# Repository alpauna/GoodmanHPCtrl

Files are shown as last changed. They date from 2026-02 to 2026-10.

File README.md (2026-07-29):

# GoodmanHPCtrl

ESP32-based controller for Goodman heatpumps with support for cooling, heating, and defrost modes.

> **⚠ Security note:** The device's web interface is plain HTTP only (no built-in TLS). For any access beyond a trusted local LAN, run it behind an HTTPS-terminating reverse proxy (Pangolin, Caddy, nginx, Cloudflare Tunnel, Tailscale Funnel, etc.) — never expose port 80 directly to an untrusted network. See [Network Access](#network-access).

## Web Interface

| Page | Screenshot |
|---|---|
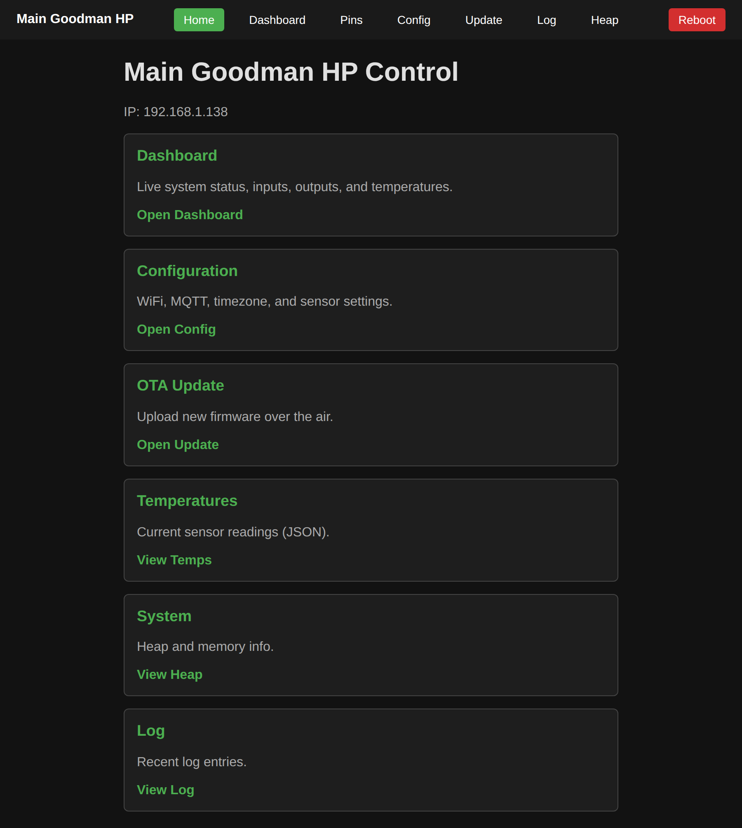
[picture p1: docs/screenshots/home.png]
Home
| Home |  |
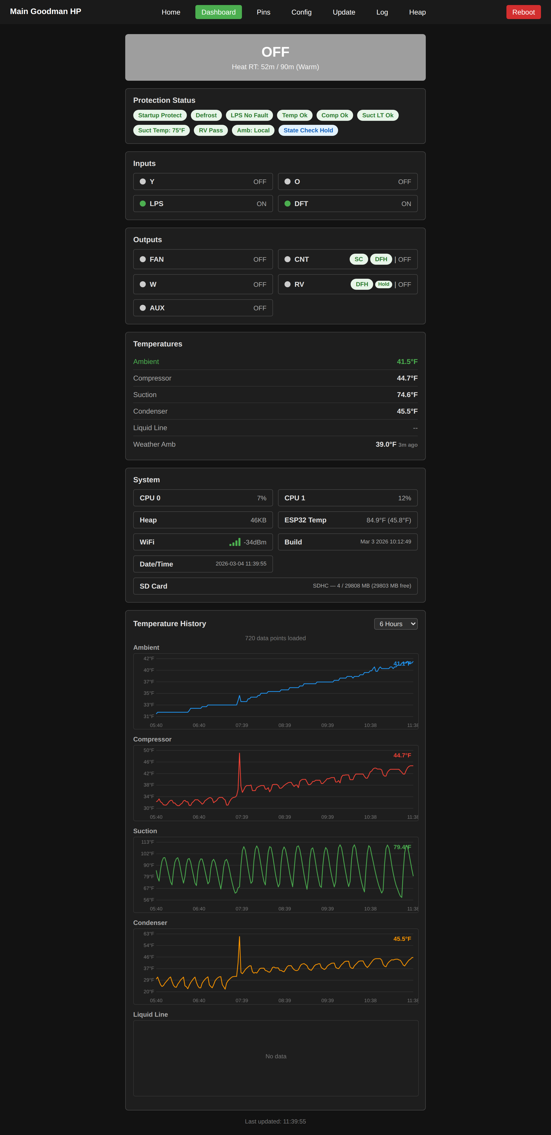
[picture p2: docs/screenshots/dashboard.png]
Dashboard
| Dashboard |  |
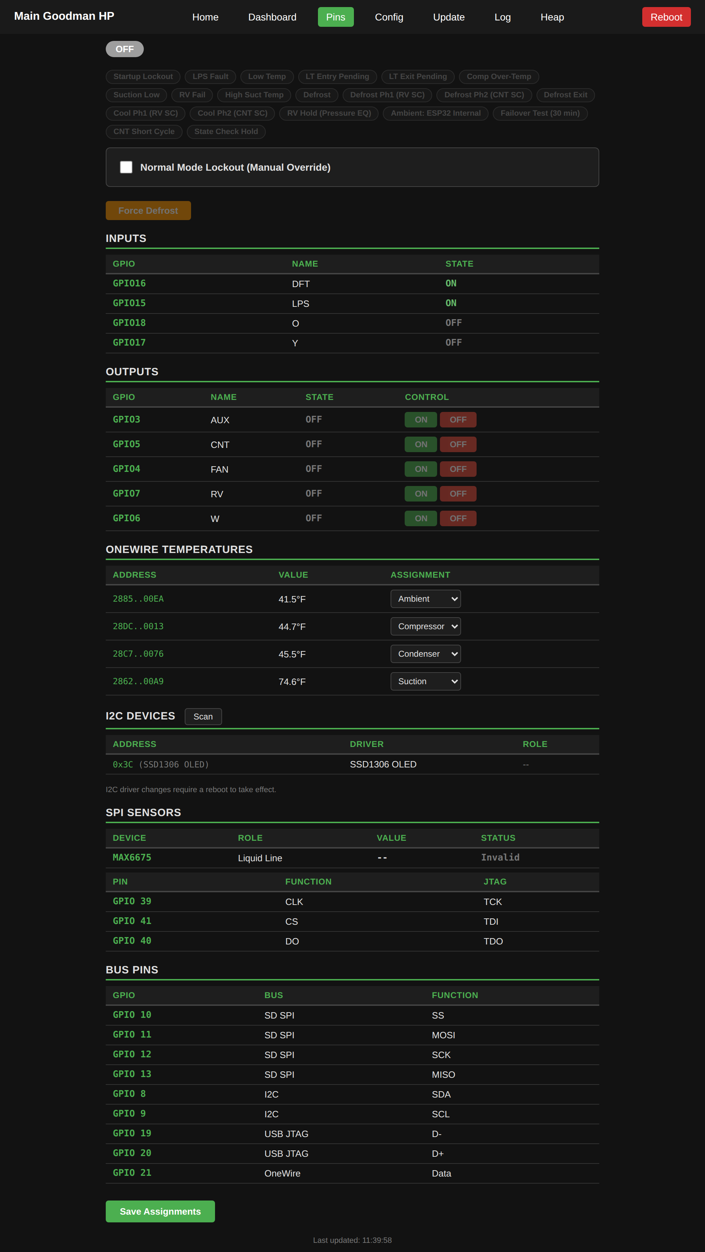
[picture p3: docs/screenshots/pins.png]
Pins
| Pins |  |
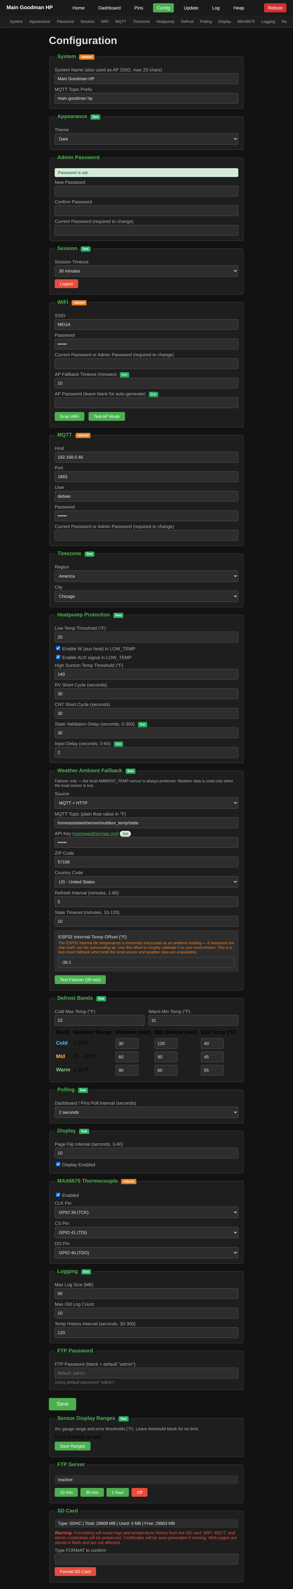
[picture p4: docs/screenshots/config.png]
Configuration
| Configuration |  |
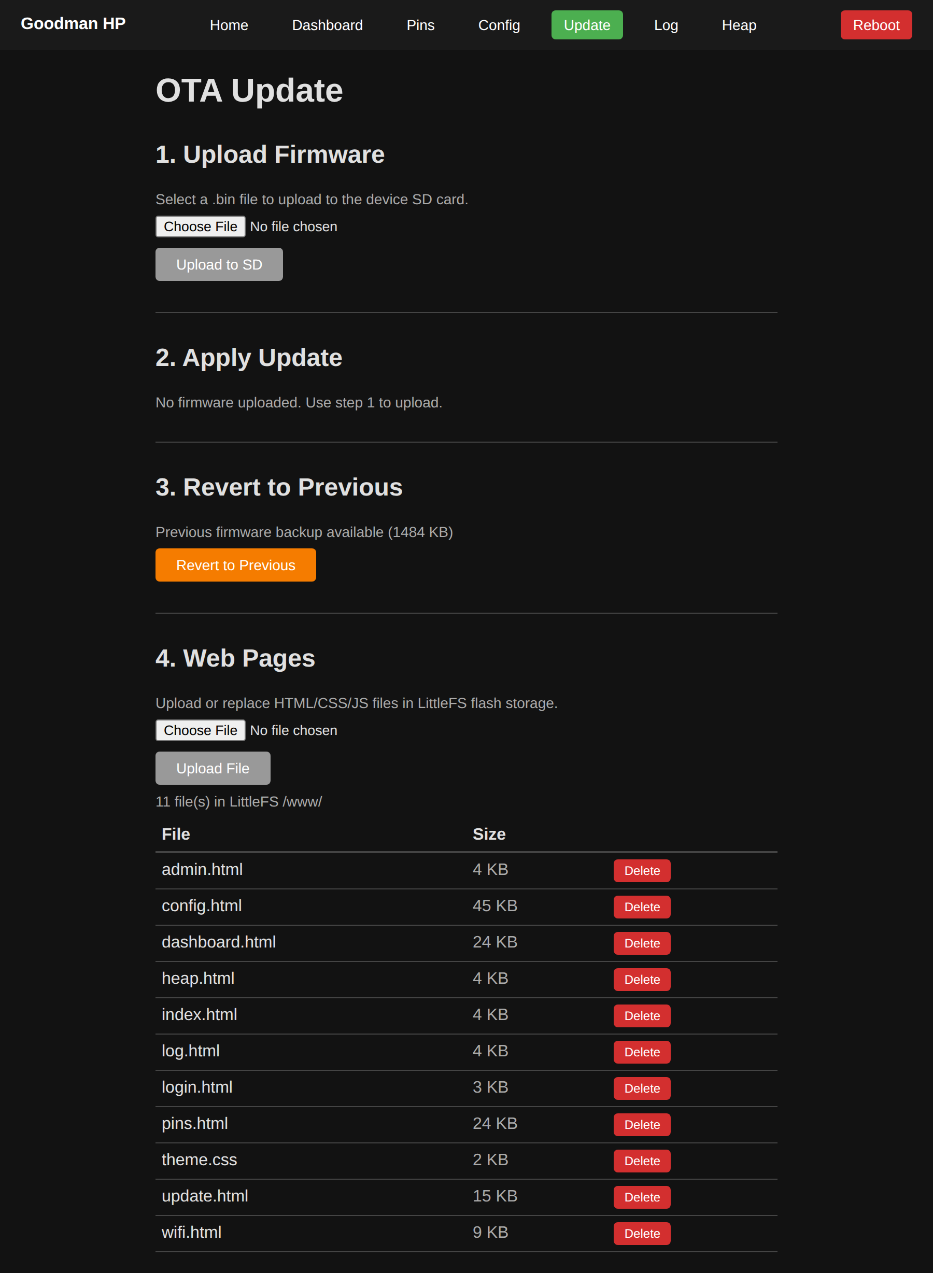
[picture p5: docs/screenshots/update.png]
OTA Update
| OTA Update |  |
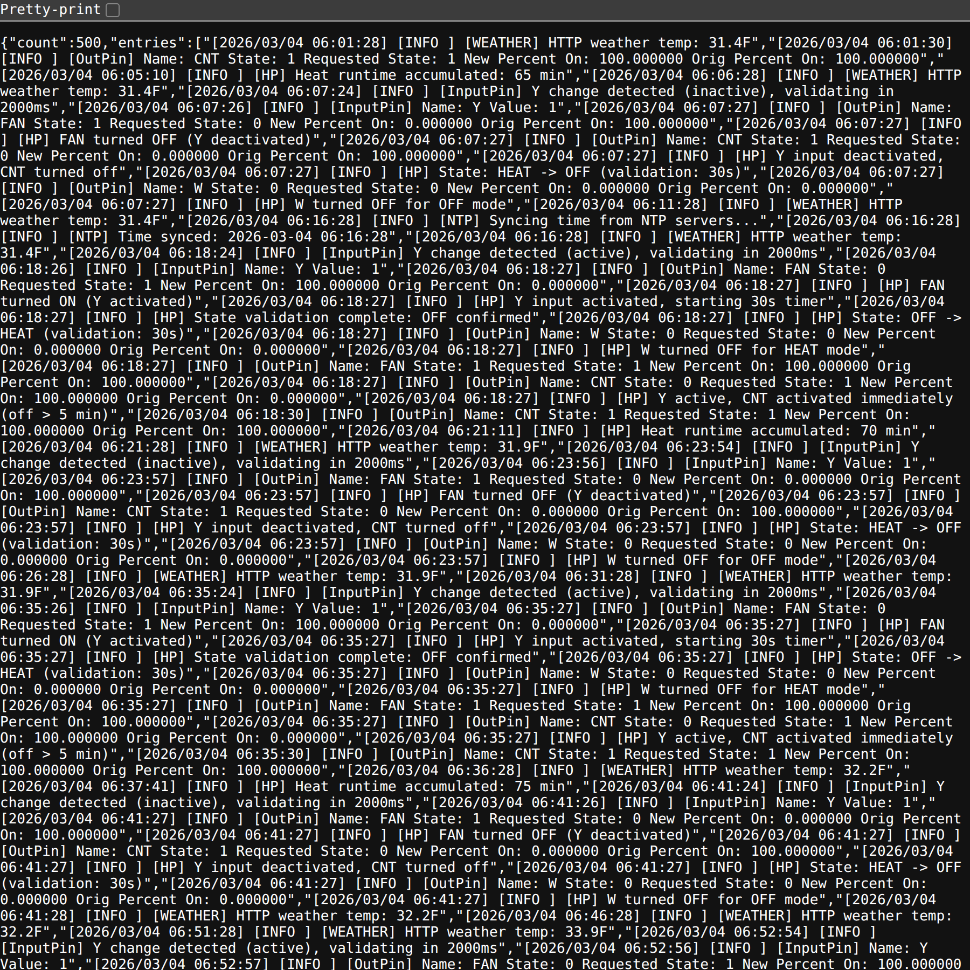
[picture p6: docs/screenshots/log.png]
Log
| Log |  |
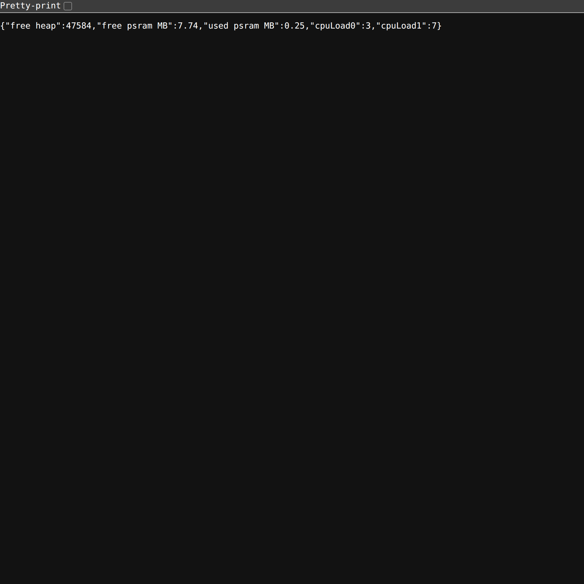
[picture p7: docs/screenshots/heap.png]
Heap
| Heap |  |

## Features

- **Relay control** — 4 output pins (FAN, Contactor, W-Heat, Reversing Valve) driven by 4 input signals (Low Pressure Switch, Defrost, Y-Cool, O-Heat)
- **Temperature monitoring** — Up to 6 OneWire (Dallas DS18B20) sensors (compressor, suction, ambient, condenser, liquid, vapor). OneWire sensors discovered on the bus are automatically merged with saved config on boot — new devices get default names and appear immediately without a config reset
- **Subcooling calculation** — Real-time subcooling diagnostic (CONDENSER_TEMP - LIQUID_TEMP) displayed on dashboard when both sensors are valid and compressor is running. Relevant for TXV systems to verify proper refrigerant charge
- **Ambient temp fallback** — 3-tier failover chain for ambient temperature: local OneWire sensor → weather data (MQTT subscription or OpenWeatherMap HTTP API, or both simultaneously) → ESP32 internal die temp. Actively fails up to the best available source every cycle. Configurable staleness timeout, test failover button, dashboard source indicator
- **Remote access** — REST API, WebSocket, MQTT (QoS 1), and CAN bus for monitoring and control
- **Dark/light theme** — Configurable dark/light theme with shared `theme.css` stylesheet. Persisted to SD card config, cached in localStorage for flash-free page loads. Instant preview on config page
- **Admin password protection** — HTTP Basic Auth on sensitive endpoints (`/config`, `/update`, `/ftp`). No password = open access
- **Password encryption** — All passwords (WiFi, MQTT, admin, FTP) encrypted at rest on SD card
- **Live dashboard** — Real-time dashboard at `/dashboard` with state banner, protection status pills with dynamic labels (LPS No Fault/Fault, Temp Ok/Low Temp, Comp Ok/OT, Suct LT Ok/LT, Suct Temp/High Suct with live temp reading, RV Pass/Fail with inline clear button), input/output grid, temperatures, and reboot button. Output indicators include inline status pills:
  - SC **SC** (Short Cycle) — Shown on CNT output. Green when inactive, red when CNT short cycle protection delay is active (CNT was off < 5 min, waiting 30s before reactivation)
  - DFH **DFH** (Defrost Hold) — Shown on CNT, W, and RV outputs during the 3-phase defrost entry and exit transitions. On RV and W: red during entry Phase 1 or exit Phase 1 (pressure equalization). On CNT: red during entry Phase 2 or exit Phase 2 (waiting for CNT short cycle before compressor starts)
- **Pin table with manual override** — Auth-protected `/pins` page showing all GPIO inputs, outputs, and temperatures in a table. "Normal Mode Lockout" checkbox enables manual output control, bypassing the state machine for up to 30 minutes (auto-timeout). CNT enforces short cycle protection even in manual mode. Single auth prompt covers the entire lockout session. "Force Defrost" button triggers a software defrost cycle from HEAT mode (requires no active faults or manual override)
- **Temperature history** — Configurable CSV logging interval (30s-5min, default 2min) per sensor to SD card (`/temps/<sensor>/YYYY-MM-DD.csv`), rolling Canvas line charts on dashboard (6 sensors) with 1h/6h/24h/7d timeframe selector, auto-purge after 31 days
- **Web-based configuration** — HTML pages served from `/www/` on SD card for configuration, OTA updates, and monitoring
- **FTP server** — SimpleFTPServer with timed enable/disable (10/30/60 min) from config page. Configurable password (encrypted on SD card); defaults to `admin`/`admin` when not set. Defaults to OFF; auto-disables after timeout
- **OTA updates** — Firmware upload saves to SD card (`/firmware.new`), then apply to flash. Automatically backs up running firmware with build date metadata before flashing. Supports manual revert and automatic crash recovery (see [Crash Recovery](#crash-recovery))
- **SD card configuration** — WiFi, MQTT, and sensor settings stored as JSON on SD card
- **Multi-output logging** — Serial, MQTT, SD card with tar.gz compressed log rotation, and WebSocket streaming
- **In-memory log buffer** — 500-entry ring buffer in PSRAM, accessible via `/log` API endpoint
- **NTP time sync** — Automatic time synchronization from NTP servers, refreshes every 2 hours
- **I2C bus** — Initialized on GPIO8 (SDA) / GPIO9 (SCL) with automatic device scan at startup and `/i2c/scan` API endpoint
- **PSRAM support** — All heap allocations routed through PSRAM when available
- **WiFi AP fallback** — Configurable timeout (default 10 minutes) before switching to Access Point mode for OTA recovery and reconfiguration
- **CAN bus integration** — Optional CAN bus (ESP32 TWAI, 250 kbps) replaces physical Y/O thermostat wires with CAN messages from AThermostat. Publishes HP state, temperatures, and heartbeat. 10-second timeout safety shuts down compressor if CAN communication is lost. DFT/LPS safety inputs always remain physical. Configurable via `can.enabled` in config JSON. See `docs/canbus-goodmanhp-implementation.md`
- **Multi-unit support** — Configurable system name (max 20 chars, alphanumeric + spaces) and MQTT topic prefix. System name is used as the web UI brand, AP SSID, OLED display name, and auth realm. Multiple controllers can publish to the same MQTT broker with unique prefixes (e.g., `unit1/temps`, `unit2/temps`)
- **FreeRTOS compatible** — Uses `vTaskDelay()` instead of `delay()` for proper RTOS task yielding

## Architecture

### GoodmanHP Controller

The `GoodmanHP` class is the central controller that manages all I/O pins and the heat pump state machine:

- **Pin Management** — Maintains `std::map` collections for input and output pins
  - `addInput(name, pin)` / `addOutput(name, pin)` — Register pins
  - `getInput(name)` / `getOutput(name)` — Access individual pins
  - `getInputMap()` / `getOutputMap()` — Access full pin collections

- **Startup** — All outputs (FAN, CNT, W, RV) are turned OFF on controller startup

- **State Machine** — Tracks heat pump operating mode:
  - `OFF` — No active request
  - `HEAT` — Y input active (heating mode, RV off, W off)
  - `COOL` — Y and O inputs active (cooling mode, RV on, W off)
  - `DEFROST` — DFT emergency defrost or software defrost cycle (W on)
  - `ERROR` — Fault condition active (LPS low pressure); CNT shut down, W follows Y in HEAT mode (Y active, O not active), state updates blocked until fault clears
  - `LOW_TEMP` — Ambient temperature below threshold (default 20°F) for 10 continuous minutes; compressor off, auxiliary heat (W) on, auto-recovers when temp stays above threshold for 10 minutes

- **Output Control by State:**
  - **RV** (reversing valve): ON in COOL, OFF in HEAT/OFF
  - **W** (auxiliary heat): ON in DEFROST, ERROR (HEAT mode only), LOW_TEMP (HEAT mode only), and RV_FAIL (HEAT mode only); OFF otherwise. In COOL mode (Y+O), the system will not operate below 20°F
  - **CNT** (contactor): auto-activates when Y input becomes active, with short cycle protection: if CNT was off for less than 5 minutes, a 30-second delay is enforced before reactivation; if off for 5+ minutes, CNT activates immediately

- **Compressor Over-Temperature Protection** — When COMPRESSOR_TEMP reaches 240°F or above:
  - Immediately shuts down CNT to stop compressor
  - Keeps FAN running to cool the compressor
  - Blocks CNT activation while overtemp is active
  - Rechecks compressor temp every 1 minute
  - Auto-recovers when temp drops below 190°F (50°F hysteresis gap)
  - Logs fault condition and resolution time
  - Highest priority fault — checked before LPS and ambient temp

- **FAN Airflow Safety (Current Watchdog)** — Guarantees the outdoor fan is actually moving air whenever the compressor (CNT) is energized. See [BUG-013](docs/bugs/013-fan-no-current-while-compressor-running.md) for the field failure that motivated this protection:
  - **CNT ⇒ FAN invariant** — every code path that turns CNT ON also asserts FAN ON in the same block (state transitions, HEAT↔COOL cancel path, short-cycle re-activation, `updateState()` output validation) so the outputs cannot desynchronize
  - **Current-based liveness** — `FAN_CURRENT` (SCT-013-030 CT on ADS1115) is polled while CNT is on; if it stays below `FAN_MIN_RUNNING_AMPS` (default 0.3 A) for `FAN_NO_CURRENT_TIMEOUT_MS` (default 20 s), CNT is shut down and the controller latches `ERROR` state for `FAN_FAULT_ERROR_MS` (default 3 min)
  - **Debounced** — requires 3 consecutive low reads before arming the 20 s timer, filtering single-sample I2C glitches from bus contention with WiFi / AsyncTCP / SD log flush
  - **Auto-recovers** after the 3-minute lockout; the watchdog re-arms on the next CNT activation and re-latches if the fan still draws no current
  - Blocks CNT re-activation while the lockout is active; public accessors: `isFanFaultActive()`, `getFanFaultRemainingMs()`, `clearFanFault()`
  - Emits grep-friendly `FAN_FAULT:` and `FAN_SAFETY:` log tags with `Y=`, `O=`, `state=`, `amps=`, `pin=`, `elapsed=` for post-mortem log forensics
  - Depends on `CurrentSensor` producing trustworthy RMS: 60-sample window over ~4 line cycles, DC-mean subtraction, and all-zero I2C reads rejected as invalid rather than published as `0.00 A`

- **Suction Low-Temperature Protection** (COOL mode only) — Monitors SUCTION_TEMP for freezing conditions:
  - Warns when suction temp drops below 34°F
  - Shuts down CNT below 32°F (critically low), keeps FAN running
  - Blocks CNT activation while fault is active
  - Rechecks every 1 minute
  - Auto-recovers when temp rises above 40°F (8°F hysteresis from critical)
  - Auto-clears if mode changes away from COOL
  - Logs fault condition and resolution time

- **LPS Fault Protection** — When the LPS (Low Pressure Switch) input goes LOW:
  - Immediately shuts down CNT if running
  - Sets state to `ERROR`, blocking all state updates
  - Blocks CNT activation while fault is active
  - W (auxiliary heat) continuously follows Y during active fault: ON when Y active and O not active (HEAT mode), OFF when Y drops or O active (COOL mode). W is never turned on in COOL mode
  - Auto-recovers when LPS goes HIGH; W turned off, short-cycle protection (30s delay) is enforced on CNT reactivation
  - Publishes fault events via MQTT (`goodman/fault` topic)

- **Low Ambient Temperature Protection** — When AMBIENT_TEMP drops below the configurable threshold (default 20°F):
  - **10-minute validation delay** in both directions: temp must stay below threshold for 10 continuous minutes before entering LOW_TEMP, and above threshold for 10 continuous minutes before exiting. If temp reverses during the validation window, the pending transition is cancelled. Prevents fluttering near the threshold
  - Enters `LOW_TEMP` state: shuts down CNT, turns off FAN and RV
  - Turns on W (auxiliary heat) in HEAT mode only
  - If thermostat switches to COOL mode (Y+O) while in LOW_TEMP, W is turned off — no heating or cooling operates below 20°F in COOL mode
  - Blocks all compressor activation (CNT) while ambient temp is too low
  - Auto-recovers when temperature stays above threshold for 10 minutes
  - Threshold is configurable via `lowTemp.threshold` in SD card config

- **Ambient Temperature Fallback (3-Tier)** — When the local AMBIENT_TEMP OneWire sensor is unavailable, the system falls through a priority chain to maintain ambient awareness:
  1. **Local sensor** (primary) — OneWire DS18B20, highest accuracy
  2. **Weather data** (failover) — Cached outdoor temperature from a configurable source:
     - **MQTT**: Subscribes (QoS 1) to a configurable topic (e.g., `homeassistant/sensor/outdoor_temp/state`) and parses plain float payloads
     - **HTTP**: Polls OpenWeatherMap API at a configurable interval (default 10 min, range 1–60)
     - **MQTT + HTTP**: Both run simultaneously — MQTT delivers faster push updates while HTTP acts as a safety net if MQTT stops publishing. Most recent update from either source wins
  3. **ESP32 internal temp** (last resort) — Die temperature via `temperatureRead()`, converted C→F. Reads higher than true ambient but catches genuinely cold conditions
  - **Fail-up**: The fallback chain re-evaluates every 10s cycle and actively promotes to the best available source — INTERNAL→WEATHER when weather data arrives, any fallback→SENSOR when the real sensor recovers
  - Weather data is cached with a configurable staleness timeout (default 30 minutes). Stale weather with no local sensor falls through to ESP32 internal temp
  - `ambientSource` field in `/state` JSON and MQTT state tracks the active source: `"sensor"`, `"weather"`, or `"internal"`
  - Dashboard shows a source-aware ambient pill (green for sensor, orange for weather/internal) and a "Weather Amb (failover)" row with the cached temperature and age
  - Output state validator enforces CNT OFF when no ambient data is available (sensor invalid + no weather)
  - Config page "Weather Ambient Fallback" fieldset: source dropdown (None/MQTT/HTTP/MQTT + HTTP), conditional MQTT topic or HTTP API key/ZIP/country fields, staleness timeout
  - **Test Failover** button on config page forces the ambient sensor offline for 30 minutes to verify the fallback chain
  - Configured via `weather` section in SD card config JSON. API key encrypted with same `$AES$`/`$ENC$` scheme as other passwords

- **Input Pin Validation Delay** — All 4 input pins (LPS, DFT, Y, O) use a configurable debounce/validation delay (default 2 seconds) to prevent false triggers from electrical noise or transient signals:
  - Input pins are polled every 500ms via `onCheckInputQueue()` (direct GPIO polling, no ISR attachment required)
  - When a pin's live GPIO state differs from its confirmed state, a validation timer starts
  - After the delay expires, the GPIO is re-read to confirm the pin is still in the expected state
  - If the pin has reverted to its original state, the change is discarded as a false trigger and logged as a warning
  - `isActive()` returns the confirmed/debounced state, not the live GPIO — the state machine only sees validated inputs
  - `getPendingState()` prevents re-triggering while a validation is already in progress
  - Both activation (pin going HIGH) and deactivation (pin going LOW) go through the full delay
  - Configurable via `heatpump.inputDelay.ms` in config JSON (0–60 seconds, live — changes apply immediately to all input pins)

- **State Validation Delay** — After any state transition (e.g., OFF→HEAT, HEAT→COOL), the system holds the new state for a configurable period (default 30 seconds) before allowing another normal-priority state change. This prevents rapid state cycling:
  - **HIGH priority** states (OFF, ERROR) bypass the validation timer entirely
  - **NORMAL priority** states (HEAT, COOL, DEFROST, LOW_TEMP) are gated — blocked until the timer expires
  - LOW_TEMP has special handling: output protection (CNT/FAN/RV off, W management) is applied immediately, but the state label is deferred until validation completes
  - Dashboard shows a "State Hold" pill (blue) with countdown during validation
  - Configurable via `heatpump.stateValidation.delayMs` in config JSON (0–300 seconds, live)

- **Output State Validation** — Every 10 seconds, `validateOutputStates()` verifies all relay outputs match the expected state for the current operating mode using a table-driven approach:
  - **Global invariants** enforced first: W must never be on when O is active; CNT must be off during any blocking fault (priority: compressor overtemp > suction low temp > LPS fault > low temp > RV fail)
  - **Per-state table** defines expected output values: OFF=all off, COOL=RV on/W off, HEAT=RV off, DEFROST Ph3=RV+W on/FAN off, ERROR=CNT off, LOW_TEMP=CNT+FAN+RV off
  - **Transition phase rows** validated: COOL Trans Ph1/Ph2, HEAT Trans Ph1/Ph2, DEFROST Ph1/Ph2, Defrost Exit Ph1/Ph2
  - Mismatches are logged as errors and auto-corrected
  - Skipped during startup lockout and manual override only (transitions are now validated)
  - Manual override also bypasses the state validation timer so it doesn't interfere with manual pin control testing
  - Logs "State check OK" at info level every 30 seconds when all outputs are correct

- **Adaptive Defrost Bands** — Colder ambient temperatures cause faster ice buildup on the outdoor coil, requiring more frequent defrost cycles. Instead of a single fixed runtime threshold, the controller uses 3 ambient temperature bands — each with its own heat runtime threshold, minimum defrost duration, and condenser exit temperature:

  | Band | Ambient Range | Runtime Threshold | Min Defrost | Condenser Exit Temp |
  |------|--------------|-------------------|-------------|---------------------|
  | **Cold** | ≤ 23°F | 30 min | 2 min | 50°F |
  | **Mid** | 23–31°F | 60 min | 1.5 min | 55°F |
  | **Warm** | ≥ 31°F | 90 min | 1 min | 60°F |

  All values are configurable via the config page "Defrost Bands" fieldset. The two breakpoint temperatures (`coldMaxTemp`, `warmMinTemp`) define the band boundaries and can be adjusted independently.

  **How it works:**
  - The active band is selected every update cycle based on the current ambient temperature (using the same 3-tier fallback: sensor → weather → ESP32 internal temp)
  - When no ambient data is available, the system defaults to the **Warm** band (most conservative — longest runtime before defrost triggers)
  - When defrost starts, the active band's parameters are **snapshotted** and frozen for the duration of the cycle. If ambient temperature drifts mid-defrost (e.g., the sun comes up), the exit criteria stay stable — no mid-cycle parameter jumps
  - Dashboard and OLED display show the current band and progress: `Heat RT: 42m / 60m (Mid)`
  - `/state` JSON includes `defrostBand` (active band name) and `defrostBandThresholdMin` (active threshold in minutes)

  **Config JSON structure:**
  ```json
  "defrost": {
      "active": false,
      "coldMaxTemp": 23.0,
      "warmMinTemp": 31.0,
      "cold": { "runtimeThresholdMs": 1800000, "minRuntimeMs": 120000, "exitTempF": 50.0 },
      "mid":  { "runtimeThresholdMs": 3600000, "minRuntimeMs": 90000,  "exitTempF": 55.0 },
      "warm": { "runtimeThresholdMs": 5400000, "minRuntimeMs": 60000,  "exitTempF": 60.0 }
  }
  ```

  **Backward compatibility:** Devices upgrading from firmware with single-value defrost settings (`heatRuntimeThresholdMs`, `minRuntimeMs`, `exitTempF`) auto-migrate on first config load. The old values become the Warm band, and Mid/Cold bands are derived proportionally. Old keys are removed on the next config save.

- **Automatic Defrost (3-Phase Sequencing)** — After the active band's heat runtime threshold of accumulated CNT runtime in HEAT mode while DFT is active (coil temp ≤ 32°F, indicating icing conditions), initiates a 3-phase software defrost cycle for safe pressure equalization and output sequencing:

  **Phase 1 — Pressure Equalization** (`defrostTransition`):
  - All outputs OFF (CNT, FAN, W, RV)
  - Duration: `heatpump.shortCycle.rv` (default 30s)
  - Allows system pressures to equalize before reversing valve switches

  **Phase 2 — RV + W Engaged, CNT Hold** (`defrostCntPending`):
  - RV and W turned ON, CNT remains OFF
  - Duration: `heatpump.shortCycle.cnt` (default 30s)
  - Allows reversing valve to fully seat before compressor starts

  **Phase 3 — Active Defrost**:
  - CNT turned ON, defrost fully active
  - Runs for at least the active band's minimum defrost time before checking exit conditions
  - Rechecks CONDENSER_TEMP every 1 minute during defrost with logging
  - Exits when CONDENSER_TEMP >= the active band's exit temperature or 15-minute safety timeout

- **Defrost Exit Transition (3-Phase)** — When defrost completes (condenser temp reached or timeout), the system performs a reverse 3-phase sequence to safely switch the reversing valve back to heat position before restarting the compressor:

  **Exit Phase 1 — Pressure Equalization** (`defrostTransition` + `defrostExiting`):
  - CNT, FAN, and W turned OFF immediately; RV stays ON
  - Duration: `heatpump.shortCycle.rv` (default 30s)
  - Allows system pressures to equalize after compressor stops

  **Exit Phase 2 — RV Switch + CNT Hold** (`defrostCntPending` + `defrostExiting`):
  - RV turned OFF (switches back to heat position), CNT remains OFF
  - Duration: `heatpump.shortCycle.cnt` (default 30s)
  - Allows reversing valve to physically seat before compressor restarts

  **Exit Complete**:
  - CNT and FAN turned ON — system resumes normal HEAT mode operation
  - State machine has already transitioned from DEFROST to HEAT at exit start

  **Additional defrost behavior:**
  - Heat runtime only accumulates when DFT input is active (closed at 32°F, indicating icing conditions)
  - DFT turning off (temps > 32°F) clears accumulated runtime after a 30-second debounce — prevents false resets from intermittent DFT wire contact
  - Only COOL and DEFROST modes clear accumulated runtime; Y going off does not
  - Only HEAT mode adds time to accumulated runtime
  - Runtime persists to SD card every 5 minutes, restored on boot
  - **Y drop during defrost entry**: All outputs turn off (including W), transition flags are cleared, but `_softwareDefrost` stays set. When Y reactivates in HEAT mode, defrost restarts from Phase 1
  - **Y drop during defrost exit**: All outputs turn off, exit transition cancelled. Normal state machine resumes on Y reactivation
  - **COOL cancellation**: If the thermostat switches to COOL mode (O becomes active) during any phase of a pending defrost, the defrost is cancelled entirely, heat runtime is cleared, and the system enters normal COOL mode

- **HEAT→COOL Mode Transition (3-Phase)** — When switching from HEAT to COOL (O input activates), the reversing valve must switch safely with the compressor stopped:

  **Phase 1 — Pressure Equalization** (`coolTransition`):
  - CNT and FAN turned OFF, RV stays OFF (from HEAT position)
  - Duration: `heatpump.shortCycle.rv` (default 30s)

  **Phase 2 — RV On + CNT Hold** (`coolCntPending`):
  - RV turned ON (switches to COOL position), CNT remains OFF
  - Duration: `heatpump.shortCycle.cnt` (default 30s)

  **Complete**: CNT and FAN turned ON — normal COOL mode active. If RV is already ON (e.g., from defrost Phase 2/3→COOL), the transition is skipped.

- **COOL→HEAT Mode Transition (3-Phase)** — When switching from COOL to HEAT (O input deactivates), the reversing valve must switch safely with the compressor stopped:

  **Phase 1 — Pressure Equalization** (`heatTransition`):
  - CNT and FAN turned OFF, RV stays ON (from COOL position)
  - Duration: `heatpump.shortCycle.rv` (default 30s)

  **Phase 2 — RV Off + CNT Hold** (`heatCntPending`):
  - RV turned OFF (switches to HEAT position), CNT remains OFF
  - Duration: `heatpump.shortCycle.cnt` (default 30s)

  **Complete**: CNT and FAN turned ON — normal HEAT mode active.

  Both mode transitions abort on Y drop or state change (fault/LOW_TEMP), turning all outputs off.

### State Table

| State | Condition | FAN | CNT | RV | W | Notes |
|---|---|-----|-----|----|---|---|
| `OFF` | Y inactive | OFF | OFF | OFF | OFF | All outputs off |
| `HEAT` | Y active, O inactive | ON | ON | OFF | OFF | CNT has 30s short-cycle protection |
| `COOL` | Y active, O active | ON | ON | ON | OFF | Will not operate below 20°F |
| `DEFROST` Phase 1 | Pressure equalization (30s) | OFF | OFF | OFF | OFF | All outputs off for pressure equalization |
| `DEFROST` Phase 2 | RV + W engaged, CNT hold (30s) | OFF | OFF | ON | ON | Reversing valve seats before compressor starts |
| `DEFROST` Phase 3 | Active defrost | OFF | ON | ON | ON | Band-specific min time/exit temp (see Adaptive Defrost Bands), 15-min safety timeout |
| `HEAT` Exit Phase 1 | Defrost exit pressure equalization (30s) | OFF | OFF | ON | ON | RV+W stay on from defrost, CNT+FAN off |
| `HEAT` Exit Phase 2 | RV switch + CNT hold (30s) | OFF | OFF | OFF | OFF | RV switches back to heat position |
| `HEAT` Exit Complete | CNT+FAN resume | ON | ON | OFF | OFF | Normal HEAT mode resumes |
| `COOL` Trans Phase 1 | HEAT→COOL pressure equalization (30s) | OFF | OFF | OFF | OFF | CNT+FAN off before RV switches |
| `COOL` Trans Phase 2 | RV on, CNT hold (30s) | OFF | OFF | ON | OFF | RV seats before compressor starts |
| `HEAT` Trans Phase 1 | COOL→HEAT pressure equalization (30s) | OFF | OFF | ON | OFF | CNT+FAN off, RV still on from COOL |
| `HEAT` Trans Phase 2 | RV off, CNT hold (30s) | OFF | OFF | OFF | OFF | RV switches to HEAT position |
| `ERROR` | LPS fault (low pressure) | OFF | OFF | OFF | ON* | *W on only in HEAT mode (Y active, O inactive) |
| `LOW_TEMP` | Ambient < 20°F | OFF | OFF | OFF | ON* | *W on only in HEAT mode; W turns off if thermostat switches to COOL (Y+O) |
| `HEAT` + RV Fail | RV fail latched | ON | OFF | OFF | ON* | *W on only in HEAT mode; CNT blocked until cleared |

**Fault Conditions** (overlay on current state, block CNT activation):

| Fault | Condition | Trigger | Recovery | FAN | CNT | W | Priority |
|---|---|---|---|-----|-----|---|---|
| Compressor overtemp | COMPRESSOR_TEMP ≥ 240°F | Any mode | Temp < 190°F | ON | OFF | OFF | 1 (highest) |
| Suction low temp | SUCTION_TEMP < 32°F | COOL mode only | Temp > 40°F | ON | OFF | OFF | 2 |
| LPS fault | LPS input LOW | Any mode | LPS goes HIGH | OFF | OFF | ON* | 3 |
| Low ambient temp | AMBIENT_TEMP < 20°F for 10 min | Any mode | Temp ≥ 20°F for 10 min | OFF | OFF | ON* | 4 |
| RV fail | SUCTION_TEMP ≥ 140°F during defrost | Defrost only | Manual clear via dashboard/config | ON | OFF | ON* | Latched |

\* W on only in HEAT mode (Y active, O inactive); never activated in COOL mode (Y+O).

**Fault Priority:** Compressor overtemp > Suction low temp > LPS fault > Low ambient temp. Higher-priority faults take precedence; lower-priority checks are skipped while a higher-priority fault is active.

### Class Structure

| Class | Purpose |
|---|---|
| `GoodmanHP` | Central controller with pin maps, temp sensors, and state machine |
| `InputPin` | Digital/analog input with polling-based validation delay, confirmed-state debouncing, callbacks |
| `OutPin` | Output relay with delay, PWM support, state tracking, hardware state validation |
| `TempSensor` | OneWire (DS18B20) temperature sensor with callbacks. 6 default names: COMPRESSOR, SUCTION, AMBIENT, CONDENSER, LIQUID, VAPOR |
| `Config` | SD card and JSON configuration management |
| `Logger` | Multi-output logging with tar.gz rotation, ring buffer, and WebSocket streaming |
| `WebHandler` | AsyncWebServer (port 80) with REST API and WebSocket |
| `MQTTHandler` | MQTT client with auto-reconnect and topic publishing |

## Hardware

**Supported boards:**
- Freenove ESP32-S3-WROOM (primary)
- ESP32 DevKit

**GPIO Pin Mapping (ESP32-S3):**

| Pin | GPIO | Direction | Description |
|-----|---|---|---|
| LPS | 15 | Input | Low Pressure Switch |
| DFT | 16 | Input | Defrost signal |
| Y | 17 | Input | Compressor request (heat or cool) |
| O | 18 | Input | Reversing valve signal (cool mode) |
| FAN | 4 | Output | Fan relay |
| CNT | 5 | Output | Contactor relay (3s delay) |
| W | 6 | Output | Heating relay |
| RV | 7 | Output | Reversing valve relay |
| SDA | 8 | I/O | I2C data |
| SCL | 9 | I/O | I2C clock |
| OneWire | 21 | I/O | Temperature sensor bus |
| CAN TX | 38 | Output | CAN bus transmit (TWAI) |
| CAN RX | 14 | Input | CAN bus receive (TWAI) |

**I2C Devices:**

| Device | Address | Description |
|---|---|---|
| SSD1306 | 0x3C | 128x64 OLED display (5-page auto-cycling status) |
| ADS1115 | 0x48 | 16-bit ADC for CT clamp current sensing |

### 3D Printed Shell

The enclosure is an EasyEDA-exported 3D shell, post-processed with FreeCAD Python scripts for thicker walls, a flipped mating profile, and mounting hardware. All files are in the `shell/` directory.

**Shell files:**

| File | Description |
|---|---|
| `3DShell_GoodmanHPv3_T_3mm_TC.step/.stl` | Original top shell (3mm walls, tongue on outer half, TC mount) |
| `3DShell_GoodmanHPv3_B_3mm.step/.stl` | Original bottom shell (3mm walls, groove on outer half) |
| `3DShell_GoodmanHPv3_T_3.5mm_TC_flipped.step/.stl` | Modified top shell (3.5mm walls, groove replaces tongue) |
| `3DShell_GoodmanHPv3_B_3.5mm_flipped.step/.stl` | Modified bottom shell (3.5mm walls, tongue replaces groove) |
| `modify_top.py` | FreeCAD script to generate the modified top shell |
| `modify_bottom.py` | FreeCAD script to generate the modified bottom shell |
| `cutout.py` | Reusable FreeCAD utility library for cutout, standoff, and mounting operations |

**Why the mating profile was flipped:** The original design had a tongue (raised band) on the top shell mating rim. When 3D printed, this thin horizontal band is prone to layer separation because it prints as an unsupported overhang at the shell's open edge. Moving the tongue to the bottom shell and the groove to the top eliminates this — the bottom tongue prints vertically up from the floor (strong layer adhesion), and the top groove is simply a recess in a solid wall.

**Modifications applied:**

1. **Wall thickening (3mm to 3.5mm)** — 0.5mm added to the outer face of all 4 walls. Inner cavity dimensions unchanged so the PCB still fits. Wall cutouts (connector openings on right and back walls) are preserved by pre-cutting matching holes in the thickening ring before fusing.

2. **Mating profile flip** — The rabbet/step joint between shells was inverted:
   - **Bottom**: Original groove (Z=31-35) filled, new outer tongue added with 0.10mm clearance per side
   - **Top**: Original tongue (Z=28-32) removed, new inner lip + outer groove cut

3. **M3 screw pillar** — 5mm OD, 3mm tall pillar on the top shell ceiling for mounting the MAX6675 thermocouple board, with M3 (2.5mm) through-hole centered in the pillar

**Utility library (`cutout.py`):**

Composable functions for shell modifications. Each takes a `Part.Shape` and returns a modified shape. OCCT boolean operation quirks (oversized plugs, Z range matching, flush trimming) are handled internally:

| Function | Purpose |
|---|---|
| `rectangular_cutout()` | Cut a window through a Z-normal surface |
| `reposition_cutout()` | Plug an existing cutout and re-cut at a new position (3-step: oversized plug, matching-Z cut, flush trim) |
| `add_standoff()` | Fuse a cylindrical pillar onto a surface (with auto-trim for reliable OCCT fuse) |
| `drill_hole()` | Vertical through-hole along Z axis |
| `drill_hole_lateral()` | Horizontal through-hole along X or Y axis (screw holes through walls) |
| `add_standoffs_with_holes()` | Multiple standoffs + centered screw holes (convenience combo) |
| `wall_ring()` | Rectangular ring (outer box minus inner box) for wall thickening and mating profiles |
| `z_probe()` | Probe Z intersections at an XY point (verification) |
| `verify_cutout()` | Check a rectangular cutout is fully open (probes center + corners) |
| `verify_solid()` | Check material exists at a point between two Z levels |

Example usage:
```python
from cutout import reposition_cutout, add_standoff, drill_hole

# Reposition an LCD cutout (plug old hole, cut new, trim flush — all in one call)
result = reposition_cutout(result,
    old_x1=-38.48, old_y1=59.59, old_x2=-11.43, old_y2=76.59,
    new_x1=-38.48, new_y1=61.59, new_x2=-11.43, new_y2=77.59,
    z_inner=48.50, z_outer=51.50)

# Add a mounting standoff below the ceiling
result = add_standoff(result, cx=-63.76, cy=67.14,
    z_surface=48.50, height=3.0, radius=2.5, z_outer=51.50)

# Drill a screw hole through the standoff
result = drill_hole(result, cx=-63.76, cy=67.14,
    z_bottom=45.50, z_top=51.50, radius=1.25)
```

**Regenerating modified shells:**

```bash
# Requires FreeCAD installed (sudo apt install freecad)
freecadcmd shell/modify_top.py
freecadcmd shell/modify_bottom.py
```

**Key geometry constants (all in mm, origin at EasyEDA export origin):**

| Constant | Value | Description |
|---|---|---|
| Outer walls | X[-98.26, 4.92] Y[-32.48, 97.12] | Original 3mm outer face |
| Inner walls | X[-95.26, 1.92] Y[-29.48, 94.12] | Original 3mm inner face |
| New outer | X[-98.76, 5.42] Y[-32.98, 97.62] | After 0.5mm thickening |
| Bottom mating zone | Z=31 to Z=35 | Groove (original) / Tongue (modified) |
| Top mating zone | Z=28 to Z=32 | Tongue (original) / Groove (modified) |
| Right wall cutout | Y[47, 88.5] Z[7, 24] | Connector opening, +X wall |
| Back wall lower cutout | X[-50, -35] Z[6, 13] | Opening, +Y wall |
| Back wall upper cutout | X[-89.5, -3.5] Z[14, 17] | Opening, +Y wall |

### Modifying EasyEDA 3D Shell Exports with Claude Code

EasyEDA exports PCB enclosures as STEP files with thin walls (typically 1.5mm). These often need post-processing — thicker walls, mating features, mounting hardware, cutouts — which can be done programmatically via FreeCAD's Python API and Claude Code. Below is a reusable prompt template and the key lessons learned from this project's shell modifications.

**Prerequisites:** `freecad` package installed (`sudo apt install freecad`), STEP files exported from EasyEDA's 3D shell generator.

**Prompt template** — adapt the bracketed sections to your project:

> I have EasyEDA-exported STEP enclosure shells at `[path/to/shells/]`:
> - `[Bottom_Shell.step]` — bottom half, open top
> - `[Top_Shell.step]` — top half, open bottom
>
> The shells have [1.5mm] walls. I need the following modifications:
>
> 1. **Wall thickening** — Increase wall thickness from [1.5mm] to [3mm] by expanding outward. Keep inner cavity dimensions identical to the original so the PCB still fits. Preserve all interior features (screw pillars, standoffs, alignment posts) from the original STEP by extracting them via boolean intersection and fusing them back into the thickened shell.
>
> 2. **Mating joint** — Add a rabbet/step joint between top and bottom shells in the overlap zone where both rims meet:
>    - Bottom: remove outer half of wall for [4mm] from the rim (groove)
>    - Top: remove inner half of wall in the overlap zone + add outer-half tongue extending [4mm] below the rim with [0.2mm] clearance
>    - The tongue must overlap at least [2mm] into existing wall geometry above the rim for OCCT fuse to succeed (coincident-face workaround)
>
> 3. **Screw holes** — Drill [M1.2] through-holes at [left and right wall midpoints], centered in the interlocking overlap zone so the screw passes through both the tongue and groove lip
>
> 4. **Cutouts** — Cut rectangular openings in the top shell for: [LCD window at X1,Y1 to X2,Y2], [wire pass-through at ...], [connector at ...]
>
> 5. **Mounting features** — Add a screw pillar on the inner ceiling of the top shell at [position] for mounting a [component]. [Xmm] OD, [Xmm] tall, [MX] tap hole
>
> Write a FreeCAD Python script (`freecadcmd script.py`) that loads the STEP files, performs all modifications via boolean operations, and exports both STL and STEP. Include a verification section that cross-sections the results and prints geometry at key Z levels.

**Key lessons for FreeCAD/OCCT boolean operations:**

| Issue | Symptom | Fix |
|---|---|-----|
| Coincident face fuse failure | `fuse()` adds volume but geometry doesn't extend beyond shared face | Extend the new body 1-2mm past the shared face into existing solid so they overlap, not just touch |
| `makeOffsetShape` fails on complex shells | Exception or degenerate result | Rebuild parametrically: create outer box, cut inner cavity, extract+fuse interior features from original via `common()` |
| Thickening shifts features | Mounting tabs, screw pillars stay at original positions | After thickening, extract features by region (`common()` with probe box), `translated()` to correct position, cut old + fuse shifted |
| Groove/tongue on wrong wall half | Joint doesn't interlock — both pieces occupy same space | Groove removes **outer** half; tongue occupies **outer** half (filling the groove space). Cut **inner** half of mating shell in overlap zone so it nests with the other shell's remaining inner lip |
| `removeSplitter()` drops geometry | Thin or newly-fused features disappear | Check volume before/after; if features vanish, skip `removeSplitter()` or increase overlap |
| STEP export loses thin features | Feature exists in memory (volume correct) but missing after reload | Ensure minimum 0.5mm thickness on all features; export STL as backup (mesh-based, more tolerant) |

**Verification pattern** — always include in your script:
```python
# Cross-section at key Z levels to verify wall profiles
for z in [key_z_values]:
    plane = Part.makePlane(250, 200, Vector(-150, -100, z), Vector(0, 0, 1))
    sec = shape.section(plane)
    sbb = sec.BoundBox
    print(f"Z={z}: X[{sbb.XMin:.2f},{sbb.XMax:.2f}] Y[{sbb.YMin:.2f},{sbb.YMax:.2f}]")
```

**Typical workflow:**
1. **Analyze** — Load STEP, print bounding boxes, cross-section at rim levels to get exact wall coordinates (outer, inner, midpoint)
2. **Thicken** — Parametric rebuild with `makeBox` + `cut` (more reliable than `makeOffsetShape` on EasyEDA exports)
3. **Interior features** — `original.common(cavity_box)` extracts pillars/standoffs, `fuse()` them into new shell
4. **Mating edge** — Groove (cut outer half) + tongue (fuse outer half extension with 2mm overlap into wall) + step (cut inner half in overlap zone)
5. **Hardware** — Screw holes (`makeCylinder` + `cut`), mounting pillars (`makeCylinder` + `fuse`), cutouts (`makeBox` + `cut`)
6. **Export** — `.exportStep()` for CAD, `MeshPart.meshFromShape()` + `.write()` for STL printing

## Getting Started

### Prerequisites

- [PlatformIO](https://platformio.org/) (CLI or IDE extension)
- USB cable connected to ESP32 board

**Linux/macOS:** Shell scripts in `scripts/` (`.sh`) require `bash` and `curl`.

**Windows:** PowerShell scripts in `scripts/` (`.ps1`) require PowerShell 5.1+ (included with Windows 10/11) and `curl.exe` (included with Windows 10+). Run with: `powershell -ExecutionPolicy Bypass -File .\scripts\<script>.ps1`

### Secrets Setup

Create `secrets.ini` in the project root (gitignored — never committed):

```ini
[secrets]
build_flags =
	-D XOR_KEY=\"your-random-base64-key\"
```

`XOR_KEY` is used as a fallback key for password encryption on the SD card when no eFuse HMAC key is provisioned (see [Password Encryption](#password-encryption)). Generate a random key with: `openssl rand -base64 32`

**AP mode password** is configured from the config page (`wifi.apPassword` in config JSON) or auto-generated randomly at runtime if not set. It is no longer a build-time constant.

### Build and Upload

PlatformIO commands work the same on all platforms:

```bash
# Build
pio run -e freenove_esp32_s3_wroom

# Upload firmware
pio run -t upload -e freenove_esp32_s3_wroom

# Serial monitor
pio run -t monitor -e freenove_esp32_s3_wroom
```

On Linux, if `pio` is not on PATH, use `~/.platformio/penv/bin/pio`. On Windows, use `%USERPROFILE%\.platformio\penv\Scripts\pio.exe`.

### SD Card Setup

The SD card should contain:

```
/config.txt              — Device configuration (WiFi, MQTT, sensors, admin password)
/www/index.html          — Home page
/www/dashboard.html      — Live dashboard with charts
/www/pins.html           — Pin table with manual override
/www/config.html         — Configuration page
/www/update.html         — OTA update page
/www/log.html            — Log viewer
/www/heap.html           — System/heap info
/www/wifi.html           — WiFi scan and setup
/www/theme.css           — Shared dark/light theme stylesheet
/temps/<sensor>/*.csv    — Temperature history CSVs (auto-created)
```

**Generate config.txt interactively:**

```bash
# Linux/macOS
./scripts/configure.sh --local

# Windows (PowerShell)
.\scripts\configure.ps1 -Local
```

This prompts for system name, MQTT prefix, WiFi, and MQTT credentials, then writes `data/config.txt`. Copy it to the SD card root. Passwords are stored in plaintext and encrypted automatically on first boot.

**Manual config.txt format:**

```json
{
  "project": "Goodman",
  "created": "Feb 06 2026",
  "description": "Goodman heatpump controller",
  "system": {
    "name": "Goodman HP",
    "mqttPrefix": "goodman"
  },
  "wifi": {
    "ssid": "your-ssid",
    "password": "your-password"
  },
  "mqtt": {
    "user": "mqtt-user",
    "password": "mqtt-password",
    "host": "192.168.0.46",
    "port": 1883
  },
  "logging": {
    "maxLogSize": 52428800,
    "maxOldLogCount": 10
  },
  "runtime": {
    "heatAccumulatedMs": 0
  },
  "timezone": {
    "gmtOffset": -21600,
    "daylightOffset": 3600
  },
  "heatpump": {
    "lowTemp": { "threshold": 20.0 },
    "highSuctionTemp": { "threshold": 140.0, "rvFail": false },
    "shortCycle": { "rv": 30000, "cnt": 30000 },
    "highAmbientLockout": { "threshold": 70.0 },
    "defrost": { "minRuntimeMs": 180000, "exitTempF": 60.0, "heatRuntimeThresholdMs": 5400000 }
  },
  "tempHistory": {
    "intervalSec": 120
  },
  "ui": {
    "theme": "dark"
  },
  "admin": {
    "password": "",
    "ftpPassword": ""
  },
  "sensors": {
    "temp": {
      "288514B2000000EA": { "description": "AMBIENT_TEMP", "name": "AMBIENT_TEMP" },
      "28C7E8B200000076": { "description": "CONDENSER_TEMP", "name": "CONDENSER_TEMP" },
      "28DCC0B200000013": { "description": "COMPRESSOR_TEMP", "name": "COMPRESSOR_TEMP" },
      "2862D5B2000000A9": { "description": "SUCTION_TEMP", "name": "SUCTION_TEMP" }
    }
  }
}
```

**Configuration options:**
- `system.name` — System display name, max 20 characters, alphanumeric + spaces (default: "Goodman HP"). Used as web UI brand, AP SSID, OLED display name, and auth realm. Requires reboot
- `system.mqttPrefix` — MQTT topic prefix (default: "goodman"). Topics become `<prefix>/temps`, `<prefix>/state`, `<prefix>/fault`, `<prefix>/log`. Requires reboot
- `logging.maxLogSize` — Maximum log file size in bytes before rotation (default: 52428800 = 50MB)
- `logging.maxOldLogCount` — Number of rotated log files to keep (default: 10)
- `tempHistory.intervalSec` — Temperature history capture interval in seconds, 30-300 (default: 120)
- `heatpump.lowTemp.threshold` — Ambient temp (°F) below which compressor is blocked (default: 20.0)
- `heatpump.highSuctionTemp.threshold` — Suction temp (°F) above which RV fail is detected during defrost (default: 140.0)
- `heatpump.shortCycle.rv` — Phase 1 pressure equalization delay in ms (default: 30000)
- `heatpump.shortCycle.cnt` — Phase 2 CNT short cycle delay in ms (default: 30000)
- `heatpump.stateValidation.delayMs` — State validation hold time in ms after state changes; prevents rapid cycling (default: 30000 = 30s, range: 0–300s, live)
- `heatpump.inputDelay.ms` — Input pin validation delay in ms; re-reads GPIO after delay to confirm state change (default: 2000 = 2s, range: 0–60s, live)
- `heatpump.defrost.minRuntimeMs` — Minimum Phase 3 runtime in ms before checking exit conditions (default: 180000 = 3 min)
- `heatpump.defrost.exitTempF` — Condenser temp (°F) at which Phase 3 exits (default: 60.0)
- `heatpump.defrost.heatRuntimeThresholdMs` — Accumulated HEAT runtime in ms before triggering defrost (default: 5400000 = 90 min, range: 1–90 min via config page)

**Log file rotation:**
- Active log: `/log.txt` (uncompressed)
- Rotated logs: `/log.1.tar.gz`, `/log.2.tar.gz`, ... `/log.N.tar.gz` (compressed)
- When `/log.txt` exceeds `maxLogSize`, it is compressed and rotated
- Oldest log is deleted when count exceeds `maxOldLogCount`
- Falls back to `.txt` extension if compression fails

**In-memory log ring buffer:**
- Stores the last 500 log entries in PSRAM for fast retrieval
- Access via `GET /log` — returns all entries as JSON
- Use `GET /log?limit=N` to return only the last N entries
- Response format:
  ```json
  {"count": 42, "entries": ["[2026/02/10 14:32:01] [INFO ] [HP] State changed", "..."]}
  ```

**WebSocket log streaming:**
- All log entries are broadcast to connected `/ws` clients in real-time
- Message format: `{"type":"log","message":"[2026/02/10 14:32:01] [INFO ] [HP] ..."}`
- Enabled by default; toggle via `POST /log/config?websocket=true|false`

**Temperature history CSV logging:**
- Logs all 6 temperature sensors (ambient, compressor, suction, condenser, liquid, vapor) at a configurable interval (30s-5min, default 2min)
- Per-sensor CSV files: `/temps/<sensor>/YYYY-MM-DD.csv` (e.g., `/temps/ambient/2026-02-11.csv`)
- CSV format (no header): `epoch_seconds,temperature_fahrenheit`
- ~56 KB/day per sensor, ~10 MB/month total across all 6 sensors
- Auto-purges CSV files older than 31 days
- Access via `GET /temps/history?sensor=<name>` API endpoint

Sensor addresses are discovered automatically on startup and can be mapped to names via this config.

### Network Access

The device has no built-in TLS — the web server (`WebHandler`, port 80) is **plain HTTP only**. This is a deliberate simplification: the device previously ran a second, self-signed HTTPS server, but that added real maintenance cost (a whole separate ESP-IDF `esp_https_server` implementation duplicating logic already in the HTTP one) without providing meaningful protection, since a self-signed cert is invisible to anything that already terminates TLS in front of it — for example, a reverse proxy or tunnel (Pangolin, Caddy, nginx, Cloudflare Tunnel, Tailscale Funnel, etc.) almost always talks plain HTTP to the origin device internally regardless of what the device itself offers.

**Important:** because everything — including Basic Auth credentials (see [Admin Password](#admin-password) below), WiFi/MQTT passwords in transit during config, and OTA firmware uploads — travels as plaintext HTTP, **this device should always run behind an HTTPS-terminating reverse proxy for any access beyond a fully trusted local LAN.** Do not expose port 80 directly to an untrusted network or the public internet.

### Admin Password

Sensitive endpoints (`/config`, `/update`, `/ftp`) are protected by HTTP Basic Auth when an admin password is set.

- **No password set** — All endpoints are open, no authentication required
- **Password set** — Browser prompts for Basic Auth (username: `admin`, password: your admin password). Since the connection itself is plain HTTP (see [Network Access](#network-access) above), these credentials are sent in an easily-reversible form — Basic Auth is not encryption. Put a reverse proxy in front for anything beyond a trusted LAN
- Set the admin password from the config page (`/config`) or via the API
- Setting a password automatically disables FTP if it was running

### Password Encryption

All passwords (WiFi, MQTT, admin, FTP) are encrypted at rest on the SD card using **AES-256-GCM** when a hardware HMAC key is provisioned, or XOR obfuscation as a fallback. Plaintext passwords are automatically encrypted on the next config save.

**Encryption tiers:**

| Tier | Method | Key Source | Prefix | Security |
|---|---|---|---|---|
| 1 (recommended) | AES-256-GCM | eFuse HMAC hardware key | `$AES$` | Key never leaves silicon — only the HMAC peripheral can access it. Cannot be extracted even with physical access to the flash/SD card |
| 2 (fallback) | XOR obfuscation | `XOR_KEY` from `secrets.ini` | `$ENC$` | Symmetric key compiled into firmware — extractable from firmware binary |
| 3 (no key) | Plaintext | None | (none) | No encryption — passwords readable on SD card |

**How it works:** On boot, the firmware calls `esp_hmac_calculate()` with eFuse BLOCK_KEY0 and a salt to derive a 256-bit AES key. The eFuse key is read-protected (`-/-`) — software cannot read it directly; only the ESP32-S3 hardware HMAC peripheral can use it to produce derived keys. Each password is encrypted with a unique random 12-byte IV (nonce), and the GCM authentication tag ensures tampering is detected.

**Provisioning the eFuse HMAC key:**

```bash
# Linux/macOS
./scripts/burn-efuse-key.sh [/dev/ttyUSB0]

# Windows (PowerShell)
.\scripts\burn-efuse-key.ps1 [-Port COM3]
```

This permanently burns a random 256-bit HMAC key to eFuse BLOCK_KEY0 with `HMAC_UP` purpose. The key block becomes read-protected and write-protected immediately after burning.

**WARNING:** eFuse burning is permanent and irreversible. Each key block can only be written once per chip. A backup of the key is saved to `efuse_hmac_key.bin` (gitignored) — store this securely.

**Verified on hardware (2026-02-22):**

```
$ espefuse.py summary (before burn)
BLOCK_KEY0: Purpose=USER, Access=R/W, Data=00 00 00 ... 00

$ espefuse.py burn_key BLOCK_KEY0 efuse_hmac_key.bin HMAC_UP
BURN BLOCK4 - OK
BURN BLOCK0 - OK

$ espefuse.py summary (after burn)
BLOCK_KEY0: Purpose=HMAC_UP, Access=-/-, Data=?? ?? ?? ... ??

Boot log:
  AES-256-GCM encryption enabled (eFuse HMAC key found)
  Admin password encryption: $AES$
  Admin password: set
```

Existing `$ENC$` passwords are automatically re-encrypted as `$AES$` on the next config save. The firmware handles all three tiers transparently — it decrypts any format and re-encrypts with the highest available tier on save.

### FTP Server

FTP (SimpleFTPServer on port 21) is used for uploading HTML files to the SD card's `/www/` directory.

- **FTP defaults to OFF** at boot
- Enabling/disabling FTP requires admin authentication (via `/ftp` API endpoint)
- Enable from the config page with timed durations (10/30/60 min), auto-disables after timeout
- **FTP password** is configurable from the config page. Stored encrypted (`$AES$`/`$ENC$`) in `admin.ftpPassword` in config JSON. When not set, defaults to `admin`. Username is always `admin`
- The `/ftp` GET status endpoint includes the active password in its response, allowing scripts to auto-detect the configured password
- **Max password length: 16 characters** (SimpleFTPServer `FTP_CRED_SIZE` limit)

**Upload web pages via HTTP:**

```bash
# Linux/macOS
./scripts/update-www.sh                          # Upload all files
./scripts/update-www.sh dashboard.html           # Upload a single file
./scripts/update-www.sh --usb [port]             # Flash via USB serial

# Windows (PowerShell)
.\scripts\update-www.ps1                          # Upload all files
.\scripts\update-www.ps1 -File dashboard.html     # Upload a single file
.\scripts\update-www.ps1 -USB [-Port COM3]        # Flash via USB serial
```

This script prompts for the device IP and admin password, then uploads files from `data/www/` to the device's LittleFS `/www/` directory via HTTP.

### WiFi AP Fallback

If the device cannot connect to WiFi for a configurable timeout (default 10 minutes), it automatically switches to Access Point (AP) mode for emergency OTA updates and configuration changes.

- **SSID:** Configured system name (default: `Goodman HP`). Set via config page or `system.name` in config JSON
- **Password:** Random 8-character alphanumeric, generated fresh on each AP activation. Displayed on the OLED screen and logged to serial
- **IP:** `192.168.4.1`
- All web endpoints work in AP mode (dashboard, config, OTA update, log, heap)
- OLED display shows AP credentials (SSID, password, IP) and holds the screen 3x longer for readability
- The device automatically attempts to reconnect to the configured WiFi every 60 seconds while in AP mode
- AP mode ends automatically when WiFi reconnects, or persists until reboot

**Recovery workflow:**
1. Check the OLED display or serial log for the AP SSID and password
2. Connect to the AP WiFi network
3. Browse to `http://192.168.4.1/config` to fix WiFi credentials
4. Or upload new firmware via `http://192.168.4.1/update`
5. The device will reconnect to WiFi automatically when credentials are corrected, or reboot to force reconnection

### Crash Recovery

The device has multiple layers of crash recovery to prevent unrecoverable states in the field.

#### Boot Watchdog / Safe Mode

An `RTC_NOINIT_ATTR` crash counter persists across software resets (cleared only on power-on). Each PANIC, INT_WDT, TASK_WDT, or WDT reset increments the counter. If it reaches 3 consecutive crash boots, the device enters **safe mode** automatically.

**Safe mode behavior:**
- Heat pump controller is fully disabled (no I/O pins, no state machine, no relay control)
- WiFi, web server, configuration, FTP, logging, CPU monitoring, and OLED display remain operational
- The OLED display shows `** SAFE MODE **` on the boot screen and protections page
- `/state` JSON includes `safeMode: true`, `crashBootCount`, and `resetReason`
- A 30-second stable boot timer resets the crash counter, so a single successful boot clears the history

**Forcing safe mode:** `POST /safemode/force` sets a one-shot config flag (`safeMode.force` in config JSON) that triggers safe mode on the next boot. The flag is automatically cleared after entering safe mode so subsequent boots are normal. Useful for maintenance or debugging.

**Clearing safe mode:** `POST /safemode/clear` clears the force flag and reboots.

#### Automatic Firmware Revert

When the device enters safe mode due to a crash boot loop (3+ consecutive crash resets) and a firmware backup exists on SD card (`/firmware.bak`), the boot watchdog automatically attempts to revert to the previous firmware.

**Build date verification:** Each OTA apply operation saves the running firmware's build date to `/firmware.bak.meta` alongside the binary backup. Before reverting, the watchdog compares the backup's build date against the currently running firmware. If they match, the backup is the same build as the crashing firmware — reverting would just re-flash the same broken code. In this case, the revert is skipped and the device continues in safe mode.

| Scenario | Backup exists | Build dates | Action |
|---|:---:|:---:|---|
| OTA update caused crash loop | Yes | Different | Auto-reverts to backup, reboots |
| Same firmware crashing | Yes | Same | Skips revert, stays in safe mode |
| No metadata file (legacy backup) | Yes | Unknown | Attempts revert (benefit of the doubt) |
| USB upload caused crash loop | No | N/A | No backup available, stays in safe mode |

**Why OTA is preferred over USB:** OTA updates (`POST /update` + `POST /apply`) automatically back up the running firmware to `/firmware.bak` with build date metadata before flashing. If the new firmware causes a crash loop, the boot watchdog can revert automatically. USB flashing (`pio run -t upload`) bypasses this entirely — no backup is created, so auto-revert is not possible. Always prefer OTA for production deployments.

#### Reboot Rate Limiting

To prevent denial-of-service via the `/reboot` endpoint, the device tracks rapid software reboots using an `RTC_NOINIT_ATTR` counter (separate from the crash counter). After 3 rapid reboots within 5 minutes, further `/reboot` API calls return `429 Too Many Requests`. The rate limit clears after 5 minutes of stable uptime.

Rate-limited reboot attempts are logged at `[ERROR] [SEC]` level with the client IP address and User-Agent header for forensic analysis.

#### Recovery Options Summary

| Problem | Recovery |
|---|---|
| Bad OTA firmware (crash loop) | Automatic: boot watchdog reverts to `/firmware.bak` |
| Bad USB firmware (crash loop) | Manual: enter safe mode (auto after 3 crashes), upload fixed firmware via web UI or OTA |
| Bad configuration | Manual: force safe mode (`POST /safemode/force`), fix config via web UI |
| WiFi credentials wrong | Automatic: AP fallback after 10 min, fix via `http://192.168.4.1/config` |
| Device unreachable | Manual: power cycle, connect via AP mode, or USB serial |
| `/reboot` DoS attack | Automatic: rate limited after 3 rapid reboots |

## Scripts

All scripts prompt interactively for required parameters (device IP, admin password, etc.). Each script has both a Linux/macOS (`.sh`) and Windows PowerShell (`.ps1`) version with identical functionality.

| Linux/macOS | Windows (PowerShell) | Description |
|---|---|---|
| `configure.sh [--local]` | `configure.ps1 [-Local]` | Configure device credentials or generate local config.txt |
| `ota-update.sh [--revert]` | `ota-update.ps1 [-Revert]` | OTA firmware upload, verify, flash, reboot, or rollback |
| `update-www.sh [file] [--usb]` | `update-www.ps1 [-File name] [-USB] [-Port COM3]` | Upload web pages to device via HTTP or USB serial |
| `backup-config.sh` | `backup-config.ps1` | Download config.txt from device for local backup |
| `restore-config.sh [file]` | `restore-config.ps1 [-File path]` | Restore config.txt to device from a local backup |
| `burn-efuse-key.sh [port]` | `burn-efuse-key.ps1 [-Port COM3]` | Burn hardware encryption key to ESP32-S3 eFuse |

**Interactive prompts** (where applicable): Device IP, Admin password, System name, MQTT prefix, WiFi/MQTT credentials, confirmation prompts. PowerShell scripts use masked input (`Read-Host -AsSecureString`) for all password prompts.

### `scripts/configure.sh` / `configure.ps1`

Configure WiFi and MQTT credentials on the device or generate a local config file for SD card provisioning. System name is validated: alphanumeric + spaces only, max 20 characters, sanitized automatically if invalid characters are entered.

```bash
# Linux/macOS
./scripts/configure.sh           # Push config to device via HTTP API
./scripts/configure.sh --local   # Generate data/config.txt for SD card

# Windows (PowerShell)
.\scripts\configure.ps1           # Push config to device via HTTP API
.\scripts\configure.ps1 -Local    # Generate data\config.txt for SD card
```

**Prompts (network mode):** Device IP, Admin password, System Name, MQTT Topic Prefix, WiFi SSID, WiFi password, Current WiFi password (if changing), MQTT host/port/user, MQTT password, Current MQTT password (if changing)

**Prompts (local mode):** System Name, MQTT Topic Prefix, WiFi SSID, WiFi password, MQTT host/port/user, MQTT password

### `scripts/ota-update.sh` / `ota-update.ps1`

OTA firmware update via HTTP. Uploads the PlatformIO build output to the device SD card, verifies the upload size, applies (backs up current firmware + flashes new), and waits for reboot.

```bash
# Linux/macOS
./scripts/ota-update.sh           # Upload and flash firmware
./scripts/ota-update.sh --revert  # Roll back to previous firmware backup

# Windows (PowerShell)
.\scripts\ota-update.ps1           # Upload and flash firmware
.\scripts\ota-update.ps1 -Revert   # Roll back to previous firmware backup
```

**Prompts:** Device IP, Admin password

**Requires:** Built firmware at `.pio/build/freenove_esp32_s3_wroom/firmware.bin`

### `scripts/update-www.sh` / `update-www.ps1`

Upload HTML files from `data/www/` to the device LittleFS `/www/` directory via HTTP, or flash the entire LittleFS image via USB serial.

```bash
# Linux/macOS
./scripts/update-www.sh                    # Upload all files over HTTP
./scripts/update-www.sh dashboard.html     # Upload a single file
./scripts/update-www.sh --usb [port]       # Flash via USB serial

# Windows (PowerShell)
.\scripts\update-www.ps1                    # Upload all files over HTTP
.\scripts\update-www.ps1 -File dashboard.html
.\scripts\update-www.ps1 -USB [-Port COM3]  # Flash via USB serial
```

**Prompts:** Device IP, Admin password

### `scripts/backup-config.sh` / `backup-config.ps1`

Download `config.txt` from the device SD card for local backup via FTP. Saves timestamped copies to `backups/<YYYYMMDD-HHMMSS>/config.txt` and a latest copy at `backups/config-latest.txt`. Automatically detects the configured FTP password from the device's `/ftp` status endpoint.

```bash
# Linux/macOS
./scripts/backup-config.sh

# Windows (PowerShell)
.\scripts\backup-config.ps1
```

**Prompts:** Device IP, Admin password

**Note:** The `backups/` directory is gitignored since config files contain credentials.

### `scripts/restore-config.sh` / `restore-config.ps1`

Restore a previously backed-up `config.txt` to the device SD card via FTP. Lists available backups for selection, validates JSON before uploading, verifies the upload size matches, and optionally reboots to load the new config. Automatically detects the configured FTP password from the device's `/ftp` status endpoint.

```bash
# Linux/macOS
./scripts/restore-config.sh                              # Pick from available backups
./scripts/restore-config.sh backups/config-latest.txt    # Restore a specific file

# Windows (PowerShell)
.\scripts\restore-config.ps1                              # Pick from available backups
.\scripts\restore-config.ps1 -File backups\config-latest.txt
```

**Prompts:** Backup selection (if no file specified), Device IP, Admin password, Reboot confirmation

### `scripts/burn-efuse-key.sh` / `burn-efuse-key.ps1`

Burn a hardware encryption key to ESP32-S3 eFuse for password encryption at rest. The key is read-protected — only the hardware HMAC peripheral can access it.

```bash
# Linux/macOS
./scripts/burn-efuse-key.sh [/dev/ttyUSB0]

# Windows (PowerShell)
.\scripts\burn-efuse-key.ps1 [-Port COM3]
```

**Parameters:** Serial port (default: `/dev/ttyUSB0` on Linux, `COM3` on Windows)

**Prompts:** Two confirmation prompts (type `yes`, then `BURN`)

**WARNING:** eFuse burning is permanent and irreversible. Each key block can only be written once per chip. A backup of the key is saved to `efuse_hmac_key.bin` (gitignored).

## API Endpoints

| Method | Path | Auth | Description |
|---|---|---|---|
| GET | `/` | | Home page with clickable cards linking to each section (served from SD `/www/index.html`) |
| GET | `/dashboard` | | Live dashboard with state, I/O, temps, and charts |
| GET | `/pins` | Yes | Pin table page / JSON (`?format=json`) with manual override control |
| POST | `/pins` | Yes | Toggle manual override, set output state, or force defrost (JSON body) |
| GET | `/state` | | Full controller state as JSON (see below) |
| GET | `/temps` | | Current temperature readings |
| GET | `/temps/history` | | Temperature history CSV data (`?sensor=<name>`, optional `&date=YYYY-MM-DD`) |
| GET | `/heap` | | Memory/heap statistics |
| GET | `/scan` | | WiFi network scan |
| GET | `/log` | | Recent log entries from ring buffer (`?limit=N`) |
| GET | `/log/level` | | Current log level |
| POST | `/log/level` | | Set log level |
| GET | `/log/config` | | Logger output configuration |
| POST | `/log/config` | | Configure logger outputs (serial, mqtt, sdcard, websocket) |
| GET | `/theme` | | Current theme and system name (`{"theme":"dark","systemName":"Goodman HP"}`) |
| GET | `/theme.css` | | Shared dark/light theme CSS stylesheet |
| GET | `/i2c/scan` | | Scan I2C bus for connected devices |
| GET | `/config` | Yes | Configuration page / JSON (`?format=json`) |
| POST | `/config` | Yes | Update configuration (JSON body) |
| GET | `/update` | Yes | OTA firmware update page |
| POST | `/update` | Yes | Upload new firmware (saved to SD as `/firmware.new`) |
| GET | `/apply` | Yes | Check if uploaded firmware exists (`{"exists":bool,"size":N}`) |
| POST | `/apply` | Yes | Flash firmware from `/firmware.new`, reboots on success |
| GET | `/revert` | Yes | Check if firmware backup exists (`{"exists":bool,"size":N}`) |
| POST | `/revert` | Yes | Revert to previous firmware from SD backup, reboots on success |
| POST | `/reboot` | Yes | Reboot the device (2s delay). Rate limited: returns 429 after 3 rapid reboots |
| POST | `/safemode/force` | Yes | Force safe mode on next boot (one-shot flag, cleared after entering safe mode) |
| POST | `/safemode/clear` | Yes | Clear forced safe mode flag and reboot |
| GET | `/ftp` | Yes | FTP server status (`{"active":bool,"remainingMinutes":N,"password":"..."}`) |
| POST | `/ftp` | Yes | Enable/disable FTP (`{"duration":N}` minutes, 0=off) |
| WS | `/ws` | | WebSocket for real-time data and log streaming |

**Auth** = Requires HTTP Basic Auth when admin password is set.

### `GET /state`

Returns the full controller state as JSON. Used by the dashboard for real-time polling.

```json
{
  "state": "HEAT",
  "inputs": { "LPS": true, "DFT": false, "Y": true, "O": false },
  "outputs": { "FAN": true, "CNT": true, "W": false, "RV": false },
  "heatRuntimeMin": 42,
  "defrost": false,
  "lpsFault": false,
  "lowTemp": false,
  "compressorOverTemp": false,
  "suctionLowTemp": false,
  "startupLockout": false,
  "startupLockoutRemainSec": 0,
  "shortCycleProtection": false,
  "rvFail": false,
  "highSuctionTemp": false,
  "defrostTransition": false,
  "defrostTransitionRemainSec": 0,
  "defrostCntPending": false,
  "defrostCntPendingRemainSec": 0,
  "defrostExiting": false,
  "stateValidating": false,
  "stateValidationRemainSec": 0,
  "manualOverride": false,
  "manualOverrideRemainSec": 0,
  "temps": { "AMBIENT_TEMP": 48.1, "COMPRESSOR_TEMP": 72.5, "SUCTION_TEMP": 65.2, "CONDENSER_TEMP": 38.7, "LIQUID_TEMP": 185.3, "VAPOR_TEMP": 52.0 },
  "subcoolingF": -146.6,
  "cpuLoad0": 23,
  "cpuLoad1": 50,
  "freeHeap": 159232,
  "wifiSSID": "your-ssid",
  "wifiRSSI": -48,
  "wifiIP": "192.168.1.136",
  "apMode": false,
  "buildDate": "Feb 12 2026 03:18:44"
}
```

| Field | Type | Description |
|---|---|---|
| `startupLockout` | bool | Whether the 5-minute startup lockout is active |
| `startupLockoutRemainSec` | number | Seconds remaining in startup lockout (0 when inactive) |
| `shortCycleProtection` | bool | Whether short-cycle protection delay is active on CNT |
| `rvFail` | bool | Whether RV fail (high suction temp during defrost) is latched |
| `highSuctionTemp` | bool | Whether suction temp is above threshold during defrost |
| `defrostTransition` | bool | Whether Phase 1 (pressure equalization) is active — entry or exit |
| `defrostTransitionRemainSec` | number | Seconds remaining in Phase 1 (0 when inactive) |
| `defrostCntPending` | bool | Whether Phase 2 (CNT hold) is active — entry or exit |
| `defrostCntPendingRemainSec` | number | Seconds remaining in Phase 2 (0 when inactive) |
| `defrostExiting` | bool | Whether a defrost exit transition is in progress (reverse 3-phase) |
| `stateValidating` | bool | Whether the state validation hold timer is active (blocking normal-priority transitions) |
| `stateValidationRemainSec` | number | Seconds remaining in state validation hold (0 when inactive) |
| `manualOverride` | bool | Whether manual override (pin control page) is active |
| `manualOverrideRemainSec` | number | Seconds remaining in manual override (0 when inactive) |
| `cpuLoad0` | number | CPU load percentage for Core 0 (WiFi/protocol stack) |
| `cpuLoad1` | number | CPU load percentage for Core 1 (Arduino loop/tasks) |
| `freeHeap` | number | Free heap memory in bytes |
| `wifiSSID` | string | Connected WiFi network name |
| `wifiRSSI` | number | WiFi signal strength in dBm |
| `wifiIP` | string | Device IP address |
| `apMode` | bool | Whether the device is in AP fallback mode |
| `buildDate` | string | Firmware build date and time (compile timestamp) |
| `subcoolingF` | number | Subcooling in °F (CONDENSER_TEMP - LIQUID_TEMP). Only present when both sensors are valid and compressor is running (HEAT/COOL/DEFROST) |
| `safeMode` | bool | Whether the device is in safe mode (crash recovery or forced) |
| `crashBootCount` | number | Number of consecutive crash boots (resets after 30s stable uptime) |
| `resetReason` | string | ESP32 reset reason (e.g., `POWERON`, `SW_RESET`, `PANIC`, `INT_WDT`) |
| `rebootRateLimited` | bool | Whether reboot API calls are rate-limited (clears after 5 min stable) |

### `GET /temps/history`

Returns temperature history CSV data for a specific sensor. Requires `?sensor=` parameter.

**List available files:**
```
GET /temps/history?sensor=ambient
→ {"files":[{"date":"2026-02-11","size":56000},{"date":"2026-02-10","size":55800}]}
```

**Download a day's CSV:**
```
GET /temps/history?sensor=ambient&date=2026-02-11
→ 1739318400,48.1
  1739318430,48.2
  ...
```

Valid sensor names: `ambient`, `compressor`, `suction`, `condenser`, `liquid`

### OTA Firmware Update Workflow

1. `POST /update` — Upload firmware binary (saved to SD card as `/firmware.new`)
2. `GET /apply` — Verify uploaded firmware exists and check size
3. `POST /apply` — Backs up running firmware to `/firmware.bak` with build date metadata (`/firmware.bak.meta`), then flashes new firmware from SD and reboots
4. `POST /revert` — Roll back to previous firmware from SD backup

If the new firmware causes a crash boot loop, the boot watchdog automatically reverts to the backup (see [Crash Recovery](#crash-recovery)).

## MQTT Topics

The controller publishes to a configurable MQTT broker (default `192.168.0.46:1883`) using **QoS 1** (at-least-once delivery) for all publishes and subscribes. The topic prefix defaults to `goodman` but is configurable via `system.mqttPrefix` in config JSON or the config page, allowing multiple units on the same broker (e.g., `unit1/temps`, `unit2/temps`).

Subscribe with `mosquitto_sub -t "goodman/#"` to receive all topics (replace `goodman` with your configured prefix).

### `goodman/log`

Log messages from the Logger. Published as plain text strings in the format:

```
[2026/02/10 14:32:01] [INFO] [HP] State changed: OFF -> HEAT
```

### `goodman/temps`

Temperature sensor readings, published whenever any sensor value changes.

```json
{
  "COMPRESSOR_TEMP": 72.5,
  "SUCTION_TEMP": 65.2,
  "AMBIENT_TEMP": 48.1,
  "CONDENSER_TEMP": 38.7,
  "LIQUID_TEMP": 185.3
}
```

Only sensors with valid readings are included. Values are in Fahrenheit.

### `goodman/state`

Full controller state, published on every state transition, fault event, and compressor overtemp change.

```json
{
  "state": "HEAT",
  "inputs": {
    "LPS": true,
    "DFT": false,
    "Y": true,
    "O": false
  },
  "outputs": {
    "FAN": true,
    "CNT": true,
    "W": false,
    "RV": false
  },
  "heatRuntimeMin": 42,
  "defrost": false,
  "defrostTransition": false,
  "defrostCntPending": false,
  "defrostExiting": false,
  "lpsFault": false,
  "lowTemp": false,
  "compressorOverTemp": false,
  "suctionLowTemp": false,
  "startupLockout": false,
  "startupLockoutRemainSec": 0,
  "shortCycleProtection": false,
  "rvFail": false,
  "highSuctionTemp": false,
  "stateValidating": false,
  "manualOverride": false,
  "coolTransition": false,
  "coolCntPending": false,
  "heatTransition": false,
  "heatCntPending": false,
  "defrostElapsedSec": 0
}
```

| Field | Type | Description |
|---|---|---|
| `state` | string | Current state: `OFF`, `HEAT`, `COOL`, `DEFROST`, `ERROR`, or `LOW_TEMP` |
| `inputs` | object | Input pin active states (true = active) |
| `outputs` | object | Output pin states (true = on) |
| `heatRuntimeMin` | number | Accumulated HEAT mode CNT runtime in minutes |
| `defrost` | bool | Whether a software defrost cycle is active |
| `defrostTransition` | bool | Whether Phase 1 (pressure equalization) is active — entry or exit |
| `defrostCntPending` | bool | Whether Phase 2 (CNT hold) is active — entry or exit |
| `defrostExiting` | bool | Whether a defrost exit transition is in progress (distinguishes exit from entry) |
| `lpsFault` | bool | Whether an LPS low-pressure fault is active |
| `lowTemp` | bool | Whether LOW_TEMP protection is active (after 10-min validation) |
| `lowTempPendingEntry` | bool | Whether temp is below threshold and awaiting 10-min entry validation |
| `lowTempPendingExit` | bool | Whether temp is above threshold and awaiting 10-min exit validation |
| `lowTempPendingRemainSec` | number | Seconds remaining in LOW_TEMP entry/exit validation (0 when inactive) |
| `compressorOverTemp` | bool | Whether compressor temperature exceeds 240°F threshold |
| `suctionLowTemp` | bool | Whether suction temperature is critically low in COOL mode (< 32°F) |
| `startupLockout` | bool | Whether the 5-minute startup lockout is active |
| `startupLockoutRemainSec` | number | Seconds remaining in startup lockout (0 when inactive) |
| `shortCycleProtection` | bool | Whether short-cycle protection delay is active on CNT |
| `rvFail` | bool | Whether RV fail (high suction temp during defrost) is latched |
| `highSuctionTemp` | bool | Whether suction temp is above threshold during defrost |
| `stateValidating` | bool | Whether the state validation hold timer is active |
| `manualOverride` | bool | Whether manual override is active from pin control page |
| `apMode` | bool | Whether the device is in AP fallback mode |

### `goodman/fault`

Fault events, published when a fault activates or clears.

```json
{
  "fault": "LPS",
  "message": "Low refrigerant pressure",
  "active": true
}
```

When the fault clears:

```json
{
  "fault": "LPS",
  "message": "Low refrigerant pressure cleared",
  "active": false
}
```

| Field | Type | Description |
|---|---|---|
| `fault` | string | Fault identifier (currently `LPS`) |
| `message` | string | Human-readable fault description |
| `active` | bool | `true` when fault activates, `false` when cleared |

## Build Notes

- **PSRAM allocation** — Global `operator new` and `operator delete` are overridden in `src/PSRAMAllocator.cpp` to route all heap allocations through PSRAM via `ps_malloc()` when available, falling back to standard `malloc()` otherwise. PSRAM is initialized early using `__attribute__((constructor(101)))`, which runs before C++ global constructors, ensuring PSRAM is available for any static object that allocates memory. The `BOARD_HAS_PSRAM` build flag must be defined in `platformio.ini` for the ESP-IDF framework to enable PSRAM support. This approach keeps allocation logic out of `main.cpp` and avoids per-allocation init checks.

- **AsyncTCP watchdog** — The `CONFIG_ASYNC_TCP_USE_WDT=0` build flag is required in `platformio.ini`. Without it, AsyncTCP subscribes its task to the ESP-IDF task watchdog (5s timeout). When the MQTT broker is slow or unreachable, the async_tcp task cannot reset the watchdog in time, causing a panic and reboot. This flag prevents the async_tcp task from registering with the watchdog.

## Major Code Cleanups

Removals of significant, previously-working subsystems, kept here since
"why isn't X here anymore" is a different question than "what's broken"
(the [Known Bugs](#known-bugs) section below).

### HTTPS server removed

The device ran a second, independently-maintained ESP-IDF
`esp_https_server` implementation of `/config` and `/update` alongside the
primary AsyncWebServer-based `WebHandler` — duplicated logic, duplicated
attack surface, self-signed cert. Removed because deployment already runs
behind an HTTPS-terminating reverse proxy (Pangolin, or equivalent — Caddy,
nginx, Cloudflare Tunnel, Tailscale Funnel), which talks plain HTTP to the
origin regardless of what the device itself offers — so the on-device
HTTPS was providing no real protection while costing real maintenance.
See [Network Access](#network-access) for the current plain-HTTP-behind-a-proxy
model and the operational requirement that follows from it.

### MAX6675 / MAX31850K / MCP9600 thermocouple support removed

`LIQUID_TEMP` had a 3-tier thermocouple auto-detect fallback chain
(`MAX6675 SPI > MAX31850K OneWire > MCP9600 I2C`) that existed on the
assumption that R-32 refrigerant temperatures at the liquid-line
measurement point could exceed the OneWire DS18B20 sensor's +125°C rating.
That assumption doesn't hold: **R-32's critical temperature is ~78°C
(172°F)** — above that it cannot exist as a liquid at any pressure, so the
liquid line can never physically read above that ceiling while there's
still liquid refrigerant there to measure, regardless of fault severity.
DS18B20 has ~85°F of margin over a limit R-32 cannot cross. `LIQUID_TEMP`
is now a plain 6th OneWire sensor, identical to the other 5 roles — plain
1-Wire DS18B20 sensors are sufficient for every temperature role on this
board; no thermocouple fallback is needed anywhere.

Removing it also measurably reduced main-loop CPU load — the MCP9600 I2C
read path (small in byte count, but MCP9600 can clock-stretch the I2C bus
while mid-conversion, and the ESP32 `Wire` driver blocks the calling task
for the full stretch) was costing significantly more than its nominal
transaction size suggested:

| | `cpuLoad1` | `loopItersPerSec` |
|---|---|---|
| Before (MCP9600/MAX6675 active) | ~42% | ~387 |
| After (removed) | ~18% | ~1000 |

MAX6675's software-SPI bit-bang read was checked directly against its
library source and confirmed negligible on its own (~330µs once per 10s,
a 0.003% duty cycle) — the CPU load drop is attributable to the MCP9600
I2C path specifically, not MAX6675, and not any change to the ADS1115
current-sensing ADC (unchanged, still I2C, unrelated to this cleanup).

## Known Bugs

All bug reports in [`docs/bugs/`](docs/bugs/).

| # | Description | Severity | Fixed In |
|---|---|---|---|
| [BUG-001](docs/bugs/001-defrost-exit-cnt-fan-with-y-inactive.md) | Defrost exit turns on CNT+FAN with Y inactive — compressor runs without indoor airflow. `_defrostStartTick=0` causes false 15-min timeout when Y drops during Phase 1/2, triggering exit sequence that turns on compressor without checking Y. Suction temp peaked at 148°F. | Critical | `028e568` |
| [BUG-002](docs/bugs/002-manual-override-bypasses-startup-lockout.md) | Manual override bypasses startup lockout — CNT can be turned ON 69 seconds after reboot during 180s lockout period. `setManualOverride()` and `setManualOutput()` did not check `_startupLockout`. Short cycle condition had redundant AND making it ineffective after 30s. | High | `6f0871c` |
| [BUG-003](docs/bugs/003-stale-sensor-false-low-temp-on-boot.md) | Config-loaded sensors marked `valid=true` on boot with stale cached `last-value: 0`. `checkAmbientTemp()` sees 0.0°F < threshold and triggers false LOW_TEMP protection on every reboot — shutting down CNT, turning on W for ~10s until real OneWire data arrives. 77 false triggers across 263 reboots in first 18-day deployment. | High | `d49d2e8` |
| [BUG-004](docs/bugs/004-w-on-during-defrost-phase1.md) | W relay turned ON during defrost Phase 1 — race condition in `updateState()` where W control block ran before Phase 1 restart set `_defrostTransition=true`. Validator auto-corrected. 6 occurrences (Feb 25–Mar 1). | Medium | `46d3a0f` |
| [BUG-005](docs/bugs/005-fan-off-after-manual-override-exit.md) | FAN not restored after manual override exit — `_yWasActive` not reset so Y activation edge never re-fired. Validator auto-corrected. 1 occurrence (Feb 25). | Low | `f7f3cf4` |
| [BUG-006](docs/bugs/006-fan-validator-fight-during-state-validation.md) | FAN validator fight during state validation window — validator enforced OFF rules against stale state label while FAN was correct for pending HEAT transition. Double-correction. 2 occurrences (Feb 28). | Low | `f7f3cf4` |
| [BUG-007](docs/bugs/007-rv-off-under-pressure-no-equalization.md) | RV relay turned off under pressure without equalization delay — 9 code paths called `rv->turnOff()` directly while system still under compressor discharge pressure. Fix: `safeRvOff()` helper defers RV off until `_rvShortCycleMs` after CNT off. | Medium | `2b8a199` |
| [BUG-008](docs/bugs/008-ota-upload-hangs-device.md) | OTA upload hangs device — HTTPS httpd task does `httpd_req_recv()` + `SD.write()` in tight loop, concurrent SD access from main loop tasks corrupts SPI bus → deadlock. Fix: buffer firmware in PSRAM, single SD write. | High | `a75ab7b` |
| [BUG-009](docs/bugs/009-defrost-triggers-in-off-state.md) | Defrost triggers in OFF state — `checkDefrostNeeded()` had no state guard before runtime threshold check, allowing defrost to start while Y inactive. Y-abort safety gate caught it within 500ms. Fix: gate new-defrost trigger on `State::HEAT`. 1 occurrence (Mar 3). | Low | `932b969` |
| [BUG-010](docs/bugs/010-defrost-band-display-stuck-warm.md) | Defrost band display stuck on Warm in OFF/COOL — BUG-009 regression. `selectDefrostBand()` was below the HEAT guard so `_activeDefrostBand` never updated outside HEAT mode. Fix: moved band selection above guard. | Low | `fd030e4` |
| [BUG-014](docs/bugs/014-main-loop-stall-from-ads1115-sample-rate.md) | Main loop stalled to ~1 iteration/sec — blocking 60-sample ADS1115 current reads at the library default 128 SPS took ~900ms/sec, starving input debounce and short-cycle/defrost timing for ~16 days. First fix (860 SPS) restored loop speed but caused a real accuracy regression (fan channel +67% vs. clamp meter) from the ADC's wider filter bandwidth at higher SPS. Non-blocking sampling state machine restored 128 SPS's accuracy without blocking, but repeated clamp-meter checks then revealed a separate, real ~20-25% CT calibration gap (config-save for current-monitoring settings was also silently broken); fixed the config backend, added a 3-point clamp-meter calibration tool, and applied corrected ctRatio values (compressor +1.3%, fan +7.7% vs. clamp meter after). Also reworked CPU load measurement, which had masked the stall by always reading 0%. | High | `9870f65`, `3c202f7`, `5c5cbf5` |
| [BUG-015](docs/bugs/015-frozen-ads1115-read-passes-as-valid-current.md) | Loose ADS1115 connection froze both current channels at a stale, non-zero raw value; the vendored `Adafruit_ADS1X15` library ignores I2C read/write failures, and a frozen (zero-variance) reading passes `CurrentSensor::tick()`'s all-zero guard as a valid `0.00A`. `checkFanFault()` correctly treated it as "no airflow" and short-cycled the production compressor into `ERROR` every ~3.5 min. Physically reseating the ADS1115 board resolved it immediately; the code gap (no detector for a frozen/stale reading, only an all-zero one) remains open. | High | not yet fixed (physical mitigation only) |
| [BUG-016](docs/bugs/016-high-ambient-lockout-leaves-cnt-fan-running-in-off.md) | High-ambient-HEAT lockout forced `_state = OFF` while Y stayed active, but nothing turned CNT/FAN off for that transition; `validateOutputStates()`'s corrective sweep was permanently disabled because `_stateValidationActive` only clears via a HEAT/COOL/DEFROST transition attempt, which never happens while parked in OFF; and `checkYAndActivateCNT()` (a second, independent CNT/FAN control path) had no awareness of the lockout and kept re-energizing them. Compressor/fan kept running against the system's own OFF decision indefinitely. Fixed all three gaps; verified live on bench under the exact reproduction (Y active, O dropped, ambient above threshold) — held OFF with all outputs off for 40+s across 8 polls. Not yet deployed to production. | High | pending commit |

## Dependencies

Managed automatically by PlatformIO. Key libraries:

- [TaskScheduler](https://github.com/arkhipenko/TaskScheduler) — Cooperative multitasking
- [DallasTemperature](https://github.com/milesburton/Arduino-Temperature-Control-Library) — OneWire sensor driver
- [ESPAsyncWebServer](https://github.com/ESP32Async/ESPAsyncWebServer) — Async HTTP/WebSocket server
- [AsyncMqttClient](https://github.com/marvinroger/async-mqtt-client) — MQTT client
- [ArduinoJson](https://github.com/bblanchon/ArduinoJson) — JSON parsing/serialization
- [ESP32-targz](https://github.com/tobozo/ESP32-targz) — tar.gz compression for log rotation
- [SD](https://github.com/espressif/arduino-esp32/tree/master/libraries/SD) — Arduino SD card library (used for all file operations)
- [SimpleFTPServer](https://github.com/xreef/SimpleFTPServer) — FTP server for SD card file uploads (STORAGE_SD mode)

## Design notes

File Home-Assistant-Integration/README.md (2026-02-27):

# Home Assistant Integration for Goodman Heat Pump Controller

This folder contains everything needed to integrate the ESP32 HVAC controller's MQTT telemetry into Home Assistant.

## MQTT Topics Published by the Controller

| Topic | Format | Published When |
|---|---|---|
| `{prefix}/temps` | JSON: `{"COMPRESSOR_TEMP":72.5,"SUCTION_TEMP":65.2,...}` | Any sensor value changes |
| `{prefix}/state` | JSON: state, inputs, outputs, faults, flags | State transitions |
| `{prefix}/fault` | JSON: `{"fault":"LPS","message":"...","active":true}` | Fault activate/clear |

Default prefix: `goodman` (configurable via `system.mqttPrefix` in device config).

The controller is **publish-only** — it does not subscribe to any command topics.

## Integration Approaches

### 1. Discovery Script (Recommended Starting Point)

**`discovery.py`** — Python script that publishes MQTT auto-discovery messages to your broker. Home Assistant automatically creates all entities grouped under a single device.

```bash
pip install paho-mqtt
python discovery.py --broker 192.168.1.1 --prefix goodman
```

**Pros:** No firmware changes, entities auto-appear in HA, device grouping works out of the box.
**Cons:** Must re-run if broker loses retained messages.

### 2. Manual YAML Configuration

**`configuration.yaml`** — Drop-in MQTT sensor/binary_sensor definitions for HA's `configuration.yaml`.

Copy the contents into your HA config (or use `!include`), restart HA or reload MQTT entities.

**Pros:** No dependencies, full control over entity names/icons.
**Cons:** Tedious to maintain, no automatic device grouping.

### 3. Firmware MQTT Discovery (Future)

Migrate the discovery payloads from the script into `MQTTHandler::publishDiscovery()` so the device self-registers with any HA instance automatically. Requires firmware changes:
- Add LWT (`{prefix}/availability` with `online`/`offline`)
- Publish retained discovery configs on MQTT connect
- Publish availability `online` after connect

### 4. Custom Integration (`custom_components/`)

A full Python integration package. Overkill for read-only telemetry but useful if bidirectional control (sending commands from HA to the controller) is added later.

## Entity Mapping

| Data | HA Entity Type | Device Class | Notes |
|---|---|---|---|
| Temperature sensors | `sensor` | `temperature` | `state_class: measurement`, unit `°F` |
| Controller state | `sensor` | `enum` | OFF/COOL/HEAT/DEFROST/ERROR/LOW_TEMP |
| Heat runtime | `sensor` | `duration` | Unit: `min` |
| Input pins (Y, O, LPS, DFT) | `binary_sensor` | — | Read-only thermostat/switch signals |
| Output relays (FAN, CNT, W, RV, AUX) | `binary_sensor` | `running` | NOT `switch` — outputs are state-machine controlled |
| Fault flags | `binary_sensor` | `problem` | lpsFault, compressorOverTemp, suctionLowTemp, rvFail, highSuctionTemp |
| Protection states | `binary_sensor` | — | lowTemp, defrost, manualOverride, stateValidating |

## Files

| File | Description |
|---|---|
| `discovery.py` | MQTT auto-discovery script (approach 1) |
| `configuration.yaml` | Manual YAML config (approach 2) |
| `README.md` | This file |

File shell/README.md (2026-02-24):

# 3D Shell Enclosure

3D-printable two-piece enclosure for the GoodmanHP controller board. Designed in EasyEDA (original STEP exports), modified with FreeCAD scripted operations.

## Files

| File | Purpose |
|---|---|
| `cutout.py` | Reusable FreeCAD utility library for shell operations |
| `modify_top.py` | Top shell modifications (mating profile, wall thickening, cutouts, labels) |
| `modify_bottom.py` | Bottom shell modifications (mating profile, wall thickening, screw holes) |
| `3DShell_GoodmanHPv3_T_3mm_TC.step` | Original top shell (3mm walls, EasyEDA export) |
| `3DShell_GoodmanHPv3_B_3mm.step` | Original bottom shell (3mm walls, EasyEDA export) |
| `*_3.5mm_*_flipped.step/.stl` | Modified shells (3.5mm walls, flipped mating profile) |

## Building

Requires FreeCAD installed with command-line access:

```bash
freecadcmd shell/modify_top.py
freecadcmd shell/modify_bottom.py
```

## Shell Dimensions

- Outer: 103.2 x 129.6 mm (after 0.5mm wall thickening)
- Inner cavity: 97.2 x 123.6 mm
- Wall thickness: 3.5mm (original 3mm + 0.5mm thickening)
- Mating zone: Z=28-35mm, tongue-and-groove with 0.1mm clearance
- M1.5 screw holes at wall midpoints for assembly

## Hinged Shell Variant

| File | Purpose |
|---|---|
| `hinge_config.py` | Shared hinge/closure constants (pin axis, knuckle layout, snap clips) |
| `modify_top_hinged.py` | Hinged top shell (knuckle hinge on left wall, snap clip pockets on right) |
| `modify_bottom_hinged.py` | Hinged bottom shell (knuckle hinge on left wall, snap clips on right) |

- 5-knuckle interleaving barrel hinge on the left wall (bottom: 0,2,4; top: 1,3)
- Pin axis at Z=35.2 (0.2mm above mating line for FDM tolerance/binding clearance)
- Snap clips on right wall at Y=20 and Y=65 for tool-free closure
- M2 screw post in front-right corner for additional clamping
- Hinge barrels use rectangular struts (not round) which act as a built-in 90-degree travel stop. To allow wider opening, replace the rectangular buildup/strut in `knuckle_hinge()` in `cutout.py` with cylindrical geometry.

```bash
freecadcmd shell/modify_top_hinged.py
freecadcmd shell/modify_bottom_hinged.py
```

## Top Shell Features

| ID | Description | Dimensions | Position (XY) | Label |
|----|---|---|---|---|
| LV | Low Voltage (24v signals) | 84x35mm | X[-89,-5] Y[0,35] | "24v Signal Wires" (debossed above) |
| HV | High Voltage (240V power) | 10.5x20mm | X[-91,-80] Y[50,70] | "240 V" (debossed above) |
| TC | Thermocouple (MAX6675) | 16x14mm | X[-71,-56] Y[72,85] | "+"/"-" polarity, "Liquid Line" (debossed below) |
| LCD | LCD Display | 27x16mm | X[-39,-11] Y[62,78] | (none) |

## Bottom Shell Features

| ID | Description | Wall | Dimensions | Position |
|----|---|---|---|---|
| ACCESS | General access/venting | Right (+X) | 41.5x17mm | Y[47,89] Z[7,24] |
| VENT | Air vent slot | Back (+Y) | 86x3mm | X[-90,-4] Z[14,17] |
| ANTENNA | ESP32 antenna clearance | Back (+Y) | 15x7mm | X[-50,-35] Z[6,13] |

## cutout.py Function Reference

### Geometry Primitives

| Function | Description |
|---|---|
| `wall_ring(...)` | Rectangular ring (outer box minus inner box) for walls, grooves, tongues |

### Cutout Operations

| Function | Description |
|---|---|
| `rectangular_cutout(shape, x1, y1, x2, y2, z_inner, z_outer)` | Cut rectangular through-hole in Z-normal surface |
| `reposition_cutout(shape, old_*, new_*, z_inner, z_outer)` | Plug existing cutout, re-cut at new position |
| `labeled_cutout(shape, x1, y1, x2, y2, z_inner, z_outer, label, ...)` | Rectangular cutout with optional debossed text label (above/below) |
| `wall_opening(shape, wall, a1, a2, z1, z2, wall_coord, ring_thick)` | Cut opening in a wall-parallel region (for thickening ring cutouts) |

### Mounting Features

| Function | Description |
|---|---|
| `add_standoff(shape, cx, cy, z_surface, height)` | Fuse cylindrical pillar onto Z-normal surface |
| `drill_hole(shape, cx, cy, z_bottom, z_top, radius)` | Vertical cylindrical hole along Z axis |
| `drill_hole_lateral(shape, axis, start, end, cy, cz, radius)` | Horizontal through-hole along X or Y axis |
| `add_standoffs_with_holes(shape, positions, z_surface, height)` | Multiple standoffs with centered screw holes |
| `max6675_mount(shape, cutout_x1, cutout_y1, z_inner, z_outer, ...)` | MAX6675 board mount: terminal cutout + 6mm offset pillar + screw hole |

### Text Operations

| Function | Description |
|---|---|
| `deboss_text(shape, text, x, y, z_surface)` | Cut text into Z-normal surface (recessed lettering) |
| `emboss_text(shape, text, x, y, z_surface)` | Raise text above Z-normal surface (protruding lettering) |

### Verification Helpers

| Function | Description |
|---|---|
| `z_probe(shape, x, y)` | Probe Z intersections at an XY point |
| `verify_cutout(shape, x1, y1, x2, y2, z_inner, z_outer)` | Verify rectangular cutout is fully open |
| `verify_solid(shape, x, y, z_inner, z_outer)` | Verify material exists at XY between Z levels |
| `print_volume(shape, label)` | Print shape volume |

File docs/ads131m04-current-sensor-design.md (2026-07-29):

# ADS131M04 SPI Current Sensor — Design Notes

**Status**: Scoping only — no hardware populated yet, no driver code written.
**Schematics**: [`SPI-Current-Sensor-Schematic.pdf`](schematics/SPI-Current-Sensor-Schematic.pdf)
(daughter board, `Board1`, v1.0, 2026-05-22) +
[`Goodman-Heatpump-Main-Board.pdf`](schematics/Goodman-Heatpump-Main-Board.pdf)
(main board, `Board1`, v1.0, updated 2026-07-27 — `H3`/`U43` are the
daughter-board interconnect)
**Datasheet**: [`ads131m04_datasheet.pdf`](ads131m04_datasheet.pdf) (TI SBAS890D, March 2019 — revised May 2021)
**Motivated by**: [BUG-014](bugs/014-main-loop-stall-from-ads1115-sample-rate.md) — the ADS1115-based
current sensing needed a software calibration fudge factor (`ctRatio`), a
hand-built non-blocking polling state machine, and still samples the two
channels ~470ms apart from each other rather than simultaneously. Also
the ADS1115 has no path to power factor or true (real) power — RMS
current is all it can give you.
**Decision**: ADS1115 is being fully retired, not kept as a fallback —
clean cutover to this SPI design. Goal now explicitly includes computing
power factor and true power, not just RMS current (see "Power factor and
true power" below).

## Why this is a real upgrade, not just a faster ADC

| | ADS1115 (current) | ADS131M04 (this schematic) |
|---|---|---|
| Resolution | 16-bit | 24-bit |
| Channels | 2 (mux'd, one at a time) | 4 (3 wired: compressor/fan/heater), **simultaneous** |
| Interface | I2C | SPI |
| Ready signal | Poll a status bit (`conversionComplete()`) | Hardware `DRDY#` line |
| Clock | Internal RC oscillator | External 8.192MHz crystal |
| Anti-alias filtering | None (raw CT signal straight to ADC) | RC low-pass per channel before the ADC |
| DC bias / offset | Software: subtract computed mean per 60-sample window | Hardware: AC-coupled into a precision 1.65V `VBIAS` (`OP07CDR` buffer) |
| Phase reference | None — sampling starts whenever the 1s task tick fires | Zero-cross detector (`ZX`) fed into `AIN2` — sampled in the same synchronized frame as every other channel |

Every one of BUG-014's pain points traces back to a limitation of the
ADS1115 approach specifically:

- **The loop-stall bug** existed because one-shot conversions had to be
  triggered and polled one at a time, in series, for each of 60 samples ×
  2 channels. Simultaneous sampling with a `DRDY#` interrupt needs zero
  busy-polling and produces both channels' data in the same SPI frame.
- **The 860 SPS accuracy regression** happened because faster ADS1115
  sampling widened its internal filter bandwidth and let more noise
  through. The ADS131M04 has a dedicated RC anti-alias filter in the
  analog front end — filtering happens once, in hardware, independent of
  the digital data rate chosen.
- **The ~20-25% ctRatio calibration gap** was diagnosed and corrected
  empirically with a clamp meter because there was no other way to know
  the ADS1115+CT+burden signal chain's real gain. A precision buffered
  bias reference and proper anti-alias filtering won't eliminate the need
  for *some* per-channel scale calibration (CT clamps themselves have
  manufacturing tolerance), but should make the starting error much
  smaller and more consistent channel-to-channel than what we measured
  tonight.
- **Compressor/fan samples ~470ms apart**: the current round-robin
  (`GoodmanHP::tickCurrentSensors()`) samples one channel to completion
  before starting the next. Simultaneous sampling means "compressor
  current" and "fan current" are always readings from the *same instant*,
  which matters for anything that ever wants to correlate the two (it
  doesn't today, but it's a correctness gap worth not having).

## Hardware overview (from the schematic)

- **`U3` — ADS131M04IRUKR**: 4-ch, 24-bit, simultaneous-sampling SPI ADC.
  All 4 channels are used: `AIN0` (compressor), `AIN1` (fan), `AIN3`
  (heater/crankcase — not currently implemented in firmware at all;
  `crankcaseCtRatio`/`crankcaseBurdenOhms`/`crankcaseExpectedAmps` exist
  in `Config.h` but have no `CurrentSensor` instance behind them), and
  **`AIN2` carries the zero-cross reference** (`AIN2P` = `ZX`, `AIN2N` =
  `AGND` — single-ended into a differential input). There is no spare
  channel on this ADC; a 5th sensor would need a second chip.
- **`U1` — 8.192MHz oscillator** on `CLKIN`, with `RESET#`/`CS#` pulled up
  (`R1`/`R2`/`R3`, 100kΩ) so the ADC idles in a safe state if the MCU's
  GPIOs are tri-stated at boot.
- **`H1`** — 7-pin header: `CS#`, `DRDY#`, `SCLK`, `DOUT`, `DIN`, `3.3V`,
  `DGND`. `RESET#`/`SYNC#` is *not* on this header — it's pulled up to
  3.3V via `R3` on the daughter board and never reaches the ESP32 (see
  "Open questions" below, now resolved).
- **`U8` — `OP07CDR`** precision op-amp, buffering a `10k`/`10k` divider
  off 3.3V into a stable `VBIAS = 1.65V` reference, fed to the three CT
  channels' bias networks (not `AIN2`/`ZX`, which is a digital signal, not
  an AC current waveform needing bias).
- **Per current channel** (compressor/fan/heater identical): CT clamp jack
  (`PJ-3200A-3A`, standard 3.5mm CT connector) → `1k`/`10nF` RC low-pass
  → `10µF` AC-coupling caps into the ADC's differential input pair, biased
  to `VBIAS` through `10k` resistors on both legs.
- **`ZX`** — a 2-pin header (`U2` on the daughter board, `U43` on the main
  board) carries the zero-cross signal from the main board's isolated
  detector (`U33`/`AT3H4B-CuH-S`) directly into `AIN2P` on `U3`, with
  `AIN2N` grounded to `AGND`. It does **not** go to an ESP32 GPIO at all —
  see the "Zero-cross synchronized windows" section below for what that
  means for firmware.

## Main-board interconnect

The main board (`Board1`, CPU page) has two connectors dedicated to this
daughter board, `H3` and `U43`, both matching the daughter board's own
connectors by pin count and part number:

**`H3` (`PM254V-11-07-H85`, 7-pin) ↔ daughter board `H1` (7-pin)** —
**confirmed pin-for-pin off the live schematic** (a straight ribbon/cable
connection — `H3` pin *N* wires directly to `H1` pin *N*, not matched by
signal-name position, which is what an earlier PDF-text-based guess got
wrong):

| `H3` pin # | Net (main board) | `H1` pin # | Net (daughter board) | Function |
|---|---|---|---|---|
| 1 | GND | 1 | DGND | ground |
| 2 | 3.3V | 2 | 3.3V | power |
| 3 | GPIO2 | 3 | DIN | SPI MOSI → ADC |
| 4 | GPIO42 (`MTMS`) | 4 | DOUT | SPI MISO ← ADC |
| 5 | GPIO1 | 5 | SCLK | SPI clock |
| 6 | GPIO46 | 6 | DRDY# | data-ready interrupt |
| 7 | GPIO45 | 7 | CS# | chip select |

`GPIO42` = `MTMS` on ESP32-S3, consistent with this repo's own prior fix
(`836cca4`, "GPIO 42 is used for DOUT (MISO)") — this board repurposes
JTAG pins as general GPIO.

No pin sharing on this bus: `SW1` → `RESET`/`CHIP_PU`, `SW2` → `GPIO0`
(the standard ESP32 boot-mode-select pin, present but unused so far on
this board) — both confirmed unrelated to `GPIO1`/`GPIO2`/`GPIO45`/
`GPIO46`/`GPIO42`. All 5 signal pins on `H3` are dedicated to this bus.

### RESET# bodge wire

`H3` is a fixed 7-position connector already on the fabricated main
board — adding an 8th conductor for `RESET#`/`SYNC#` isn't possible
through it as-is. Instead of waiting for a board respin, run a separate
bodge wire that bypasses `H3` entirely:

- **Tap point (daughter board)**: `R3`'s non-3.3V pad — the side tied to
  the `RESET#`/`SYNC#` net and `U3` pin 10 (`SYNC#/RESET#`). Easier to
  solder to than the QFN pin directly, and doesn't disturb `R3` itself.
- **Destination (main board)**: `GPIO39` — one of the three pins
  (`39`/`40`/`41`) freed by tonight's MAX6675 removal (formerly
  CLK/CS/DO). Not a strapping pin, not PSRAM/flash-reserved, and already
  proven safe on this exact board — it carried real SPI traffic for
  months without any boot-mode issues. No new solder point needed here:
  the main board schematic already has a populated JTAG debug header
  (`3.3V`/`MTDO`/`MTDI`/`MTCK`/`MTMS`) that breaks `GPIO39`/`MTCK` out to
  a proper pin — a single-pin female header socket onto that connector's
  `MTCK` position is the whole connection on this end.
- **Wiring**: `GPIO39` as `OUTPUT_OPEN_DRAIN`, configured once in
  `setup()`. `digitalWrite(HIGH)` releases the pin (high-Z), letting
  `R3`'s existing 100kΩ pull-up hold `RESET#`/`SYNC#` at its normal idle
  state — this is the default/safe state, including before `setup()`
  ever runs. `digitalWrite(LOW)` actively pulls `RESET#`/`SYNC#` low to
  assert a hardware reset. `R3` stays in place; nothing on the daughter
  board changes.
- **Not yet done**: this is a documented plan, not yet wired. Bring-up
  sketch support (`bringup/ads131m04/main.cpp`) is ready — send `r` over
  Serial to pulse `GPIO39` low and confirm the ADC recovers (`ID`/`STATUS`
  re-read correctly, `DRDY#` resumes toggling) — so it's testable as soon
  as the bodge wire is soldered.

**`U43` (`ZX-PM2.54-1-2PY`, 2-pin: `ZX`/`AGND`)** — separate from `H3`,
matching the daughter board's own 2-pin `ZX`/`AGND` header. `ZX` originates
on the triacs page at `U33` (`AT3H4B-CuH-S`), an opto-isolated zero-cross
detector sensing the 24VAC line directly (isolated ground domain
`E-GND`), with its output pulled up to 3.3V through `R28` (33kΩ) —
**inverse logic**: the phototransistor conducts and pulls `ZX` toward
ground whenever there's enough AC amplitude to drive it, releasing back
toward the 3.3V rail only in the brief window around each zero crossing
(confirmed on scope: narrow ~120Hz upward pulses on an otherwise-low
baseline, matching two release windows per 60Hz cycle). Destination:
wired into `AIN2P` on the daughter board's ADC (`AIN2N` tied to `AGND`),
so the ADS131M04 samples it as a 4th channel in the same synchronized
frame as the current channels. No interrupt, no GPIO, no separate timing
domain.

**Needs a voltage divider — not a direct connection.** Originally assumed
to be a "clean 3.3V logic signal" safe to feed straight into `AIN2P`; live
scope measurement (right at the ADC pin) showed peaks up to `+2.94V`,
which is nearly 2.5x the ADS131M04's `±1.2V` full-scale at gain=1. Overdriving
the front-end that far doesn't just clip cleanly — it produced an
apparent full-negative-scale reading on every cycle in addition to the
expected positive clip, even though the real analog signal (confirmed on
two independent scope captures, at two different drive amplitudes) never
goes negative at all. Likely modulator/filter saturation from the severe
overdrive, not a wiring fault.

Fix (divider only, not a ground-reference rework — see reasoning below):
tap a divider off the existing `ZX` node, after `R28`, before `AIN2P`:
- `R_top = 220kΩ` from `ZX` to a new tap point, `R_bottom = 110kΩ` from
  the tap point to ground — a clean 1:3 ratio, `3.3V × 1/3 = 1.1V` at the
  ADC even at the theoretical full-rail worst case (worse than the 2.94V
  actually measured), leaving ~8% headroom under the 1.2V ceiling.
- Total divider impedance (330kΩ) is deliberately ~10x `R28`'s 33kΩ, so
  it doesn't meaningfully load the existing pull-up (~10% reduction in
  achieved high level, acceptable).
- **Considered and rejected**: also moving the phototransistor's ground
  reference from `COM`/`GND` to `AGND` directly (eliminating even the
  small offset `FB1`, ~0.1-0.16Ω, introduces between `COM` and `AGND`).
  Rejected because it would require reworking both boards for a benefit
  that doesn't matter here — this channel's job is detecting *when* an
  edge happens (phase-angle timing), not measuring absolute voltage, and
  a few tens of millivolts of offset doesn't shift edge-crossing timing
  on a signal swinging most of a volt. Worth revisiting only if testing
  turns up something that specifically points to needing it.
- Not yet installed — divider only, existing `R28`/opto/ground wiring
  unchanged.

## Firmware architecture (proposed)

### Split acquisition from accumulation

Today, `CurrentSensor` owns both the ADC I/O (`beginSample()`/`tick()`
talking to `Adafruit_ADS1115`) and the RMS math. That made sense for a
mux'd single-channel-at-a-time ADC where each sensor genuinely does its
own independent acquisition. It doesn't fit a simultaneous-sampling ADC,
where one `DRDY#` event produces data for *all* channels at once.

Proposed split:

- **New `SPICurrentADC` class** (or similar) owns the ADS131M04: SPI
  transport, `DRDY#` interrupt handling, register configuration
  (gain/OSR/data rate), and zero-cross synchronization. On each `DRDY#`
  event it reads one frame (all channel words in one SPI transaction) and
  pushes `{channel, rawCounts}` samples out.
- **`CurrentSensor` simplifies** to a pure accumulator: keep the existing
  `sumV`/`sumSquares`/`peak`/`nonZeroCount` accumulation and the
  AC-RMS math (mean-subtract, variance, sqrt, ×`ctRatio`) and
  `checkProtections()`, but drop `beginSample()`/`tick()`'s ADC-talking
  responsibilities — it just receives pushed samples from
  `SPICurrentADC` and finalizes when its window is full.
- **`GoodmanHP` drops the round-robin** (`tickCurrentSensors()`,
  `_currentSampleIt`/`_currentSamplingActive`) entirely — that machinery
  exists solely because the ADS1115 can only look at one channel at a
  time. With simultaneous sampling there's nothing to round-robin.

### `DRDY#`-driven acquisition, not polling

Attach an ISR (or a very short debounce + flag pattern, matching how
`InputPin` already does ISR → queued-event → scheduler-task handling in
this codebase) to `DRDY#`'s falling edge. The ISR should do the minimum
possible (set a flag / bump a counter) and let a normal-priority
scheduler task do the actual SPI transaction — same pattern already used
for `_isrEvent`/`_tGetInputs` in `GoodmanHP`, so this fits the existing
architecture rather than introducing a new one.

### Zero-cross synchronized windows

No GPIO interrupt involved — `ZX` isn't wired to the ESP32 at all. It's
fed into `AIN2P` (`AIN2N` = `AGND`) on the ADC itself, so every `DRDY#`
frame that delivers compressor/fan/heater samples *also* delivers a
zero-cross-channel sample, already time-aligned with the others by the
ADC's simultaneous-sampling architecture. This is a cleaner mechanism
than a second interrupt would have been: no ISR latency, no separate
timing domain to reconcile against the current channels, nothing to
synchronize — it's synchronized by construction.

Firmware-side, zero-cross detection becomes a software job on the
`AIN2` sample stream instead of a hardware edge interrupt: watch
consecutive `AIN2` readings for a sign change (or a threshold crossing,
depending on what `ZX`'s actual signal shape looks like once the board's
in hand — likely a clean square wave given the opto-isolated source, in
which case this is a simple "did the sign flip since last frame" check).
`SPICurrentADC` (or `CurrentSensor` for the `AIN2` channel specifically)
starts/stops each RMS accumulation window on those detected transitions
instead of on an arbitrary task-tick boundary — same goal as originally
described (windows covering an exact integer number of half-cycles), just
achieved by watching a sampled channel rather than timestamping a GPIO
edge.

One consideration for when the board's in hand: `ZX` is a 3.3V-ish
digital square wave feeding an ADC input whose common-mode/PGA range may
not be designed for a full-rail digital swing — worth confirming `AIN2`
reads sensibly (not clipped/saturated) rather than assuming it "just
works" because the signal is clean at the source.

### SPI protocol (confirmed against the TI datasheet, SBAS890D)

- **Mode**: SPI mode 1 (CPOL=0, CPHA=1) — data launched/changed on `SCLK`
  rising edges, latched on falling edges. Full-duplex: `DIN` and `DOUT`
  are both active every clock, not request/response.
- **Word size**: configurable 16/24/32-bit via `WLENGTH[1:0]` in the
  `MODE` register (address `02h`). Commands/responses/CRC words always
  carry 16 bits of real data (zero-padded to fit a wider word); ADC data
  is nominally 24-bit, truncated for 16-bit words or LSB-padded/MSB-sign-
  extended for 32-bit words. 24-bit is the reset default.
- **Frame structure**: a minimum 6-word frame in the default (4-channel,
  no output CRC disabled) configuration — word 1 is the command (`DIN`)
  and simultaneously the *previous* command's response (`DOUT`); the
  device then shifts out channel 0-3 data on `DOUT` while `DIN` is
  don't-care/zero, followed by a CRC word. `RREG`/`WREG` touching more
  than one register extend the frame accordingly. Ending a frame early
  (dropping `CS`) is safe — a new frame always starts fresh — except a
  `RESET` command specifically requires the full 6-word frame to latch.
- **Commands** (`Table 8-11`): `NULL` (`0000h`, response = `STATUS`
  register — this is also what a plain read-data cycle looks like),
  `RESET` (`0011h`, acks `FF24h` when a full frame completes), `STANDBY`
  (`0022h`), `WAKEUP` (`0033h`), `LOCK`/`UNLOCK` (`0555h`/`0655h`),
  `RREG`/`WREG` (`101a aaaa annn nnnn` / `011a aaaa annn nnnn`, where
  `aaaaa` is the starting register address and `nnnnnn` is register
  count minus one).
- **`DRDY#`**: active low, configurable via `MODE` register bits —
  `DRDY_SEL[1:0]` picks which channel's timing drives the pin (default
  `00b` = most-lagging enabled channel; `01b` = logic-OR of all enabled
  channels, likely the right choice here since all 4 channels need to be
  captured together anyway), `DRDY_HiZ` (push-pull vs. open-drain idle,
  default push-pull/driven-high — matches the plan to attach a GPIO
  interrupt directly, no external pull-up needed), `DRDY_FMT` (level vs.
  fixed-duration pulse, default level/low-until-read).
- **Registers relevant to bring-up** (`Table 8-12`, full map is 0x00-0x17+):
  - `03h CLOCK` — `CH0_EN`..`CH3_EN` (bits 8-11, **all four default
    enabled** — no explicit enable step needed for `AIN2`/`ZX`), `OSR[2:0]`
    (bits 4:2, default `011b` = 1024; lower OSR = faster data rate at
    the cost of noise — worth tuning once real noise/timing numbers are
    available on hardware), `PWR[1:0]` (default `10b` = high-resolution).
  - `04h GAIN1` — one register holds `PGAGAIN0[2:0]`..`PGAGAIN3[2:0]`,
    default `1` (`000b`) for all channels. `AIN2`/`ZX` almost certainly
    wants gain=1 (it's already a full-swing digital signal, no
    amplification needed); the CT channels' gain is a separate tuning
    question from `ctRatio` — real per-channel gain here, not just the
    software scale factor.
  - `01h STATUS` (read-only) — per-channel `DRDY0`..`DRDY3` flags,
    `CRC_ERR`, `LOCK` state. Also what a `NULL` command returns.
  - Per-channel `CHn_CFG`/`CHn_OCAL`/`CHn_GCAL` registers (`09h`+) —
    hardware phase-delay calibration (244ns resolution, per the Features
    list) and offset/gain calibration per channel. Not required for a
    first bring-up, but notable: this could eventually replace or
    complement the `AIN2` zero-cross approach for fine inter-channel
    timing, if that level of precision ever matters.
- **Not yet needed for this design**: CRC configuration (`REGCRC_EN`,
  `RX_CRC_EN`, `CRC_TYPE`), global-chop mode, current-detect mode (`CFG`
  register) — all real features but outside what compressor/fan/heater/
  zero-cross RMS monitoring requires.

### Calibration

The 3-point clamp-meter calibration tool added in `config.html` tonight
(`toggleCtCalib()`/`captureCtRow()`/`computeCtCalibration()`) should carry
over with no changes — it operates on whatever `ctRatio` the backend
reports, independent of which ADC is producing the underlying reading.
`AIN2` is committed to the zero-cross reference (not available for a 4th
current sensor), so a `heaterCtRatio`/third `CurrentSensor` for the
now-wired crankcase channel (`AIN3`) is still the only remaining channel
to add — the ADC has no free channel beyond that.

### Power factor and true power

This is the actual reason `AIN2`/`ZX` exists, not an afterthought: with
all 4 channels sampled simultaneously, the ADC provides everything needed
to compute power factor via the phase-angle method, without a dedicated
scaled-voltage channel:

1. **Voltage zero-crossing** — already established: detect sign changes
   in the `AIN2` sample stream (the line-voltage zero-cross reference).
2. **Current zero-crossing, per channel** — the *same* sign-change
   detection applied to `AIN0`/`AIN1`/`AIN3`'s own sampled RMS waveform
   data (not just used for RMS accumulation — the raw samples already
   have everything needed for this, no extra acquisition required).
3. **Phase angle** — the time delta between a current channel's
   zero-crossing and the nearest `AIN2` zero-crossing, converted to
   degrees/radians using the line period (nominally 1/60Hz, or measured
   directly from consecutive `AIN2` zero-crossings for accuracy against
   real line frequency drift).
4. **Power factor** ≈ `cos(phase angle)` — the standard displacement
   power factor calculation, appropriate for a predominantly inductive
   motor load (compressor, fan). This is *not* the same as true power
   factor for a non-linear/harmonic-rich load (e.g. a VFD), which would
   need full instantaneous `P = V(t) × I(t)` integration over a cycle —
   worth being explicit that this method's accuracy assumption is "motor
   load with roughly sinusoidal current," which fits a PSC/scroll
   compressor and PSC fan motor.
5. **True (real) power** = apparent power × PF = `(V_nominal × I_rms) ×
   cos(phase angle)`. **Caveat**: there is no channel measuring line
   voltage *magnitude* — `AIN2` only gives phase timing, not amplitude —
   so `V_nominal` has to be a configured constant (e.g. 240V for the
   compressor circuit) rather than a live measurement. True power
   computed this way is only as accurate as that assumed voltage stays
   close to the real supply voltage. A meaningfully more accurate design
   would add a scaled *voltage* channel (resistor-divider or small PT)
   instead of/alongside the zero-cross-only reference — worth keeping in
   mind if power accuracy (not just PF) ever needs to be better than
   "assumes nominal line voltage."

## Open questions

1. ~~**`ZX` signal characteristics and destination**~~ — **resolved**:
   clean, isolated 3.3V logic square wave from an opto-isolated
   zero-cross detector (`U33`/`AT3H4B-CuH-S`) on the main board, fed
   directly into `AIN2P` on the ADC (`AIN2N` = `AGND`) — not a GPIO at
   all. See "Zero-cross synchronized windows" above for the firmware
   implication (software edge-detection on a sampled channel, not a
   hardware interrupt).
2. ~~**`RESET#`/`SYNC#` wiring**~~ — **re-opened, then re-resolved**:
   originally decided not worth wiring up (see "Main-board interconnect"
   below for why a hardware reset line is worth having — the short
   version: the SPI `RESET` command depends on the SPI link itself still
   being coherent, which is exactly what can't be assumed if the ADC's
   frame sync gets corrupted; a hardware pin doesn't have that
   dependency, and it's the same lesson BUG-015 already taught about the
   old I2C ADS1115 having no recovery path short of physically reseating
   the board). Decision: **bodge wire to `GPIO39`**, not a new `H3`
   connector pin — `H3` is a fixed 7-position part (`PM254V-11-07-H85`)
   on the already-fabricated main board, so an 8th pin means a new PCB
   revision, not something addable through the existing connector. See
   "RESET# bodge wire" below for the concrete plan.
3. ~~**ESP32 pin assignment**~~ — **resolved**, confirmed pin-for-pin off
   the live schematic (not inferred from PDF text): GPIO2 (DIN), GPIO42
   /`MTMS` (DOUT), GPIO1 (SCLK), GPIO46 (DRDY#), GPIO45 (CS#). No pin
   sharing — `SW2` is on `GPIO0` (boot-select), not this bus.
4. ~~**Exact SPI frame/register protocol**~~ — **resolved**, confirmed
   against the actual TI datasheet (SBAS890D, not assumed from memory).
   See "SPI protocol" above for commands, frame structure, and the
   specific registers needed for bring-up.
5. ~~**Whether the ADS1115 stays populated as a fallback**~~ —
   **resolved**: clean cutover. ADS1115 is retired, not kept as a
   config-selectable fallback. `CurrentSensor`/`GoodmanHP` don't need to
   support both ADC types.
6. **Will a loose/marginal SPI connection produce the same silent-freeze
   failure as [BUG-015](bugs/015-frozen-ads1115-read-passes-as-valid-current.md)?**
   Lower risk, but **not automatically avoided by switching to SPI** —
   the new driver has to actually use the tools SPI provides, since
   nothing does that by default:
   - The I2C failure mode was specifically a *shared, open-drain* bus
     where a failed transaction leaves the ADS1115 library's internal
     buffer holding stale data with no error surfaced. SPI's point-to-point
     `DIN`/`DOUT`/`SCLK`/`CS#` lines don't have the same "silently NACK and
     keep the old value" failure shape — a loose connection is more likely
     to produce garbage bits or a dead line than a clean freeze.
   - However, this design's own "SPI protocol" section above lists CRC
     (`REGCRC_EN`/`RX_CRC_EN`) as **"not yet needed for this design"** —
     if the driver doesn't check the CRC word every frame includes, a
     corrupted read from a marginal connection can still look like valid
     data, the same class of bug as BUG-015, just via a different
     transport.
   - `DRDY#` is the other line of defense worth using deliberately: the
     bring-up test plan below already confirms it toggles once, but the
     production driver should also watch that it *keeps* toggling at the
     expected cadence — a `DRDY#` that stops changing is directly
     analogous to the frozen ADS1115 register and just as detectable, but
     only if something actually watches for it.
   - **Recommendation for the real driver** (not needed for the bring-up
     sketch): enable CRC on both read and write, reject any frame with a
     CRC mismatch, and add a "no `DRDY#` transition in N ms while a
     conversion should be in progress" watchdog — both are cheap, direct
     analogues of the stale-value detector proposed as the still-open fix
     for BUG-015.

## Next steps

Main board is now healthy (D1 replaced, power supply confirmed stable,
firmware flashed, WiFi/MQTT/config verified) — this is what unblocked
actually connecting the daughter board.

1. ~~**Physically connect the daughter board**~~ — **done**: connected to
   `H3` (7-pin: GND, 3.3V, GPIO2/DIN, GPIO42/DOUT, GPIO1/SCLK, GPIO46/DRDY#,
   GPIO45/CS#) and `U43` (2-pin: `ZX`/`AGND`).
2. ~~**Minimal SPI bring-up sketch first**~~ — **done**, `bringup/ads131m04/main.cpp`
   (standalone PlatformIO environment `ads131m04_bringup`, fully separate
   binary from the main firmware — see `platformio.ini`). First pass came
   back with `ID`/`STATUS` reading `0x000000` and `DRDY#` stuck low despite
   `CS#` and `SCLK` both scoping clean at the ADC — traced with a scope,
   pin by pin, to a bad solder joint on `DOUT` (`U3` pin 12 → `H3` pin 4 is
   a direct, unbuffered trace per the schematic, so once `CS#`/`SCLK`/the
   crystal all checked out, `DOUT` open was the only thing left). Reflowing
   the chip fixed it — `ID`/`STATUS` now read non-zero and `DRDY#` toggles
   normally. Run it with `pio run -e ads131m04_bringup -t upload -t monitor`.
3. **Then verify each channel is sampling something sane**: `AIN2`
   (zero-cross reference) — **done**, see "RESET# bodge wire" era work
   below and the `ZX` divider fix. `AIN0` (compressor), `AIN1` (fan),
   `AIN3` (heater) against a clamp meter, same verification method used
   for the ADS1115 calibration work — **blocked on new CT clamps**, not
   yet done.
4. **No `SPICurrentADC`/`CurrentSensor` integration yet** — this pass is
   pure hardware bring-up (does the SPI bus work, do the channels read
   plausible values), not writing the production driver class described
   above. Confirm the hardware first, then build the real driver on top
   of a known-working bring-up sketch.
5. **Deliberately provoke a bad connection** (gently wiggle/partially
   unseat `H3` while the bring-up sketch is running) and confirm this is
   actually observable — `DRDY#` stops toggling and/or a CRC check fails
   — rather than the driver quietly continuing to report the last-good
   values. This is the direct SPI-side test for the failure class in
   [BUG-015](bugs/015-frozen-ads1115-read-passes-as-valid-current.md); if
   the bring-up sketch can't tell "connector wiggled" from "still fine,"
   that's a sign CRC/`DRDY#` watchdog logic needs to be added before the
   real driver is written, not after.

## Next PCB revision requirements

The current daughter board is bench-verified working (`AIN2`/`ZX` confirmed
correct, `RESET#` confirmed working end-to-end), but only after several
rounds of hand-rework: a cold `DOUT` solder joint from the original
assembly (see step 2 above), a lifted via while cutting the `ZX` trace for
the divider, and two bodge wires (`RESET#`, the `ZX` divider) that were
never part of the original layout. Rather than continue patching this
board, fold everything learned into a clean revision:

1. **`RESET#`/`SYNC#` as a real connector pin**, not a bodge wire to the
   main board's JTAG header. Either expand `H3`/`H1` to 8 pins, or add a
   dedicated pin the way `ZX`/`AGND` already gets its own 2-pin `U43`/`U2`
   header — either is better than routing a signal through a debug header
   that happens to expose the right GPIO. Main-board side: `GPIO39`
   (`MTCK`), confirmed safe and unused after the MAX6675 removal.
2. **`ZX` voltage divider built into the layout**, not spliced onto the
   trace afterward. Confirmed working values: `220kΩ` (top, from `ZX`) /
   `100kΩ` (bottom, to local `AGND`) — a ~1:3.2 ratio, giving comfortable
   headroom under the ADS131M04's `±1.2V` full-scale even at the
   3.3V-rail worst case, without meaningfully loading `U33`'s `R28`
   pull-up (divider impedance ~320kΩ, ~10x `R28`'s 33kΩ). Reference
   `R_bottom` to the same local `AGND` net `AIN2N` already uses, not
   `COM`/`GND` — keeps the whole `ZX` chain in one ground domain without
   needing the bigger (rejected, see "RESET# bodge wire" era discussion)
   rework of moving the phototransistor's own ground reference.
3. **Via/pad robustness in the `ZX`/`AGND` area** — this specific area
   is where a via got lifted during the divider rework on the current
   board. Worth reviewing trace/via sizing and pad-to-trace transitions
   here specifically, not just as a generic design rule.
4. **CRC + `DRDY#` watchdog in the real driver** (not a layout change,
   but a requirement that should ship with this revision rather than
   be an afterthought) — per open question #6 above and the BUG-015
   failure class: enable CRC on read/write, reject frames that fail it,
   and watch that `DRDY#` keeps toggling at the expected cadence rather
   than just toggling once at bring-up. A marginal connection on this
   board already caused one silent-looking failure (`DOUT` open, caught
   by chance because nothing responded at all rather than responding
   with stale data) — don't rely on that being obvious every time.
5. **Not required, but worth a note**: the elevated `DRDY#` toggle rate
   (~1580/s vs. the ~110/s baseline) observed after fixing the lifted
   via hasn't been explained — current working theory is noise pickup
   on the open (no CT clamp yet) analog channels from the new bodge
   wiring, worth confirming once real CT clamps are connected. If it
   turns out to be a real `DRDY#`-line signal integrity issue rather
   than open-channel noise, that's relevant input for this revision's
   routing too.

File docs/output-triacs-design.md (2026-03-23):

# 24VAC/240V Triac Output Design

**Document Version:** 1.1
**Date:** 2026-03-23 (Updated)
**Application:** GoodmanHP HVAC Controller (ESP32-S3)
**Outputs Controlled:** LT (24VAC, open-drain), CNT (24VAC), W (24VAC), O-RV/FAN (240V)

---

## Overview

All four output channels use isolated optocoupler drivers with gate resistors and phantom loads. Key design features:

- **Optocoupler isolation** between ESP32 (3.3V) and high-voltage AC circuits
- **Inverted logic** on LT output (normally-closed relay behavior via MOSFET)
- **Double isolation** on 240V FAN circuit (MOSFET + zero-cross optocoupler) for safety
- **Differentiated phantom loads** based on output stage current capacity
- **Gate resistors** for controlled triac gate current limiting
- **Snubber capacitors** for EMI suppression

---

## Circuit Architecture

### Output Stages

| Output | Voltage | Driver IC | Gate Resistor | Logic | Isolation | Current Limit |
|---|---|---|---|---|---|---|
| **LT** | 24VAC | MOC3041SM | R30 (4.7kΩ phantom) | Inverted (Q1 MOSFET) | Single | ~50mA (opto open-drain) |
| **CNT** | 24VAC | KMOC3021S | R25 (180Ω) | Normal | Single | Higher (external gate drive) |
| **W** | 24VAC | KMOC3021S | R44 (180Ω) | Normal | Single | Higher (external gate drive) |
| **FAN** | 240V | MOC3041SM | R35 (390Ω) | Normal | **Double (Q2 MOSFET)** | Higher + isolation |

---

## Circuit Details

### LT Output (24VAC Open-Drain, Normally-Closed Logic)

**Topology:**
```
IO3 (3.3V) → R22 (180Ω) → Q1 (MOSFET gate)
                             │
                    Q1 inverts signal
                             │
                    U29 (MOC3041SM LED)
                             │
                    Optocoupler output (open-drain)
                             │
           Phantom Load: R30 (4.7kΩ) + C30 (470nF)
                             │
                      External system
```

**Design Rationale:**
- **Inverted logic:** MOSFET Q1 pulls opto LED to ground when IO3 is HIGH, implementing normally-closed relay behavior (HIGH = OFF)
- **Lower current capacity:** MOC3041SM is open-drain output (~50mA max)
- **Lighter phantom load:** C30 = 470nF (not 2.2µF) to avoid overloading the low-current opto output
  - Xc at 60Hz = 5.65kΩ (impedance-matched to low-capacity output)
  - Phantom load: 4.7kΩ || 5.65kΩ ≈ 2.65kΩ effective impedance

**Component Values:**
| Component | Value | Function |
|---|---|---|
| R22 | 180Ω | GPIO current limiting (3.3V input) |
| R23 | 180Ω | MOSFET source resistor |
| R26 | 10kΩ | MOSFET pull-up to 3.3V |
| Q1 | L2N7002SLLT1G | Logic inverter (HIGH on IO3 = Q1 ON = LED pulled LOW) |
| U29 | MOC3041SM | Zero-cross optocoupler for 24VAC |
| R30 | 4.7kΩ | Phantom load resistor (reduced value due to low output current) |
| C30 | 470nF | Phantom load capacitor (lower value, Xc = 5.65kΩ @ 60Hz) |
| C32 | — | **Removed** (no snubber needed; LT is open-drain output, not driving inductive load) |

---

### CNT/W Outputs (24VAC with Gate Resistor Drive)

**Topology:**
```
IO5/IO6 (3.3V) → R43/R46 (180Ω) → U27/U34 (KMOC3021S)
                                      │
                              Triac driver output
                                      │
                  Gate Resistor: R25/R44 (180Ω)
                                      │
                        External triac gate
                                      │
           Phantom Load: R31/R47 (4.7kΩ) + C33/C38 (2.2µF)
```

**Design Rationale:**
- **Higher current capability:** KMOC3021S is optimized for triac gate current (~10-50mA typical)
- **Standard gate resistor:** 180Ω limits gate current to ~26mA @ 5V (safe for triacs)
- **Proper phantom load:** 4.7kΩ + 2.2µF matches design spec
  - Xc at 60Hz = 1.2kΩ (balanced impedance matching)
  - Prevents external triac from floating high when control signal is removed

**Component Values:**
| Component | Value | Function |
|---|---|---|
| R43/R46 | 180Ω | GPIO current limiting |
| U27/U34 | KMOC3021S | Instantaneous-trigger optocoupler-triac driver |
| R25/R44 | 180Ω | Triac gate current limiting (~26mA @ 5V) |
| R31/R47 | 4.7kΩ | Phantom load resistor |
| C33/C38 | 2.2µF | Phantom load capacitor (Xc = 1.2kΩ @ 60Hz) |
| C31/C37 | 100nF | Snubber across 24VAC output |

---

### FAN Output (240V with Double Isolation)

**Topology:**
```
IO4 (3.3V) → R39 (180Ω) → Q2 (MOSFET gate)
                            │
              Q2 switches opto LED input
                            │
              U31 (MOC3041SM zero-cross)
                            │
              Gate Resistor: R35 (390Ω)
                            │
                  External FAN circuit
                            │
         Phantom Load: R42 (4.7kΩ) + C35 (2.2µF)
         Snubber: C60 (220nF)
```

**Design Rationale:**
- **Double isolation:** MOSFET Q2 provides first barrier, zero-cross optocoupler provides second
- **Higher gate resistor:** R35 = 390Ω (vs 180Ω for 24VAC)
  - Provides additional voltage isolation on the 240V side
  - Reduces gate current to ~10mA @ 5V (conservative for 240V safety)
- **Zero-cross triggering:** MOC3041SM waits for AC zero-crossing before triggering
  - Reduces EMI on 240V circuit (critical at high voltage)
  - Slower response (~10ms) acceptable for FAN application
- **Heavier snubber:** C60 = 220nF (vs 100nF for 24VAC)
  - 240V has higher dV/dt (faster voltage transients)
  - Better EMI suppression needed for main power circuits

**Component Values:**
| Component | Value | Function |
|---|---|---|
| R39 | 180Ω | GPIO current limiting (3.3V side) |
| Q2 | L2N7002SLLT1G | MOSFET isolation barrier (240V side protection) |
| U31 | MOC3041SM | Zero-cross optocoupler for 240V isolation |
| R35 | 390Ω | Gate resistor with enhanced isolation (~10mA @ 5V) |
| R42 | 4.7kΩ | Phantom load resistor |
| C35 | 2.2µF | Phantom load capacitor (Xc = 1.2kΩ @ 60Hz) |
| C60 | 220nF | **Heavy snubber** for 240V EMI suppression |

---

## Phantom Load Design Philosophy

Phantom loads are sized based on **output stage current capacity**, not a one-size-fits-all approach:

### LT (Low-Capacity Output)
- **Optocoupler open-drain:** ~50mA max
- **Phantom load:** 470nF (Xc = 5.65kΩ) — lighter to avoid overload
- **Total impedance:** ~2.65kΩ effective

### CNT, W, FAN (Higher-Capacity Output)
- **Triac gate drive:** 10-50mA typical
- **Phantom load:** 2.2µF (Xc = 1.2kΩ) — standard impedance matching
- **Total impedance:** ~1.2kΩ effective

**Design Benefit:** Each output stage operates within safe current limits while maintaining proper AC impedance matching for the driven loads.

---

## Gate Resistors

### Gate Drive Resistors (Opto Output → Gate)

| Circuit | Gate Drive Resistor | Current @ 5V | Purpose |
|---|---|---|---|
| **LT** | N/A (open-drain output) | — | N/A |
| **CNT/W (24VAC)** | 180Ω | ~26mA | Standard triac gate limiting |
| **FAN (240V)** | 390Ω | ~10mA | Enhanced isolation, reduced current for safety |

### Gate Pull-Down Resistors (Gate → COM) — Optimized

| Circuit | Pull-Down Resistor | Current @ 5V | Purpose |
|---|---|---|---|
| **CNT/W (24VAC)** | 10kΩ | ~0.5mA | Anti-false-trigger pull-down |
| **FAN (240V)** | 10kΩ | ~0.5mA | Anti-false-trigger pull-down |

**Design Evolution:**
- **Original (180Ω pull-down):** Too aggressive for ~50mA optocoupler budget
  - 27.8mA pull-down current maxed out opto output when gate was held low
  - Starved gate charging current from opto LED
- **Optimized (10kΩ pull-down):** Industry standard for triac gate circuits
  - 0.5mA pull-down (minimal opto loading)
  - Reliably holds gate to ground when opto is off
  - Prevents false triggering from capacitive coupling
  - Let's opto provide full ~50mA for gate charging during turn-on

---

## Snubber Capacitor Design

| Circuit | Snubber Value | Xc @ 60Hz | Purpose |
|---|---|---|---|
| **LT** | — | — | **Removed** (no inductive load; open-drain output only) |
| **CNT, W (24VAC)** | 100nF | 26.5kΩ | Standard EMI suppression for external triac |
| **FAN (240V)** | 220nF | 12kΩ | **Heavier snubber** for 240V higher dV/dt |

**Rationale:**
- **LT:** Removed optimization — output is just open-drain opto driver, not driving inductive triac load
- **CNT/W:** 100nF standard for 24VAC triac switching suppression
- **FAN:** 240V has higher dV/dt than 24VAC; 220nF (~2x capacity) needed for better high-frequency attenuation

---

## Optocoupler Selection

### MOC3041SM (Zero-Cross, used on LT & FAN)
- **Triggering:** Waits for next AC zero-crossing after LED illumination
- **Benefits:** Reduced EMI, lower capacitive load
- **Drawback:** ~10ms max delay (one-half cycle at 60Hz)
- **Use case:** LT (low-current open-drain), FAN (high-voltage 240V)

### KMOC3021S (Instantaneous, used on CNT & W)
- **Triggering:** Immediate when LED is illuminated
- **Benefits:** Fast response, simple drive
- **Drawback:** Higher EMI potential
- **Use case:** CNT/W (standard 24VAC triac gates, needs fast response)

---

## Test Recommendations

### Static Tests
1. **Verify optocoupler isolation** (100V insulation test)
2. **Measure gate resistor voltage drop** under load
3. **Check phantom load impedance** at 60Hz with oscilloscope

### Dynamic Tests
1. **Measure gate drive pulse width** (should be <2ms for triac latching)
2. **Verify snubber attenuation** with 240V triac switching transients
3. **Check for false triggers** with high-frequency noise injection (EFT test)

### Functional Tests
1. **LT normally-closed logic:** IO3 HIGH = output OFF, IO3 LOW = output ON
2. **CNT/W normal logic:** IO5/IO6 HIGH = output ON
3. **FAN zero-cross triggering:** Measure ~10ms delay on rising edge

---

## Design Trade-offs & Decisions

| Design Choice | Rationale | Alternative Considered |
|---|---|---|
| **Differentiated phantom loads (470nF vs 2.2µF)** | Match output current capacity | Uniform 2.2µF (would overload low-current LT) |
| **Zero-cross triggers (MOC3041SM) on LT & FAN** | Reduce EMI (especially for 240V) | Instantaneous (faster but noisier) |
| **Double isolation on 240V (MOSFET + opto)** | Maximum safety for main power | Single optocoupler (adequate but less safe) |
| **Higher gate resistor on 240V (390Ω vs 180Ω)** | Voltage isolation margin | 180Ω (simpler, but less isolation) |
| **Heavier snubber on 240V (220nF vs 100nF)** | Suppress higher dV/dt | 100nF (simpler, but more EMI) |

---

## References

- **KMOC3021S Datasheet:** Optocoupler-Triac Driver (instantaneous trigger)
- **MOC3041SM Datasheet:** Zero-Cross Optocoupler (zero-crossing trigger)
- **L2N7002SLLT1G Datasheet:** Small-signal MOSFET for logic inversion/isolation
- **Input circuit design:** See `docs/input-circuit-design.md`
- **Output schematic:** See `docs/output-triacs-schematic.pdf`

---

## Revision History

| Date | Version | Author | Change |
|---|---|---|---|
| 2026-03-23 | 1.1 | Design | Optimized snubber and gate pull-downs: removed LT snubber (no inductive load), changed gate pull-down resistors from 180Ω to 10kΩ to reduce optocoupler loading |
| 2026-03-23 | 1.0 | Design | Initial triac output design documentation; analyzed phantom load differentiation, gate resistor selection, and 240V double-isolation architecture |

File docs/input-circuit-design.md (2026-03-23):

# 24V AC Input Circuit Design

**Document Version:** 1.1
**Date:** 2026-03-23
**Application:** GoodmanHP HVAC Controller (ESP32-S3)
**Inputs Protected:** LPS, DFT, Y, O (24V AC triac-driven sources)

---

## Overview

All four digital inputs (LPS, DFT, Y, O) use identical 24V AC signal conditioning and protection circuits. The design provides:
- **Multi-stage RC filtering** for 60Hz AC attenuation
- **Reverse polarity protection** against wiring faults
- **Precise 3.3V GPIO clamping** with Zener regulation
- **Predictable timing** via 1MΩ bleed resistor
- **Current limiting** to protect ESP32 pins
- **Phantom triac load network** to prevent floating high when triac output is unloaded

---

## Circuit Schematic

```
24V AC Input (Triac-Driven)
    │
    └─── R5 (33kΩ) ───┬─── D15 (1N4148) ─── C48 (10µF) ─── D17 (SMF5.0A) ─── R80 (2.2kΩ) ─── IO15
                       │                                                           │
                    C46 (10µF)                                                    D16 (BZT52C3V3)
                       │                                                           │
                      GND                                                         GND
                                                                        C47 (100nF)
                                                                            │
                    Phantom Triac Load (prevents floating)                 GND
                       │
                    R (4.7kΩ, RC2010FK-074K7L)
                       │
                    C (2.2µF, Xc = 1.2kΩ @ 60Hz)
                       │
                      GND
```

---

## Component Specifications

### Stage 1: Input Current Limiting & Decoupling

| Component | Value | Function | Notes |
|---|---|---|---|
| **R5** | 33kΩ, 1/4W | Current limiting from 24V AC source | Peak current: ~0.73mA (safe) |
| **C46** | 10µF, ≥50V ceramic/film | Primary decoupling, 60Hz AC filtering | τ = 33kΩ × 10µF = 330ms |

**Performance:**
- RC time constant: **330ms** (low-pass filter for 60Hz noise)
- Peak current: 24V / 33kΩ = **0.73mA**
- Power dissipation: 24² / 33000 ≈ **17.5mW RMS** (acceptable)

---

### Stage 2: Transient Protection & Secondary Decoupling

| Component | Value | Function | Notes |
|---|---|---|---|
| **D15** | 1N4148W-7-F | Fast switching diode (transient clamp) | 75V reverse rating; ~0.7V forward drop |
| **C48** | 10µF, ≥50V ceramic/film | Secondary decoupling after protection diode | Works with R79 for predictable discharge |

**Performance:**
- Blocks transient spikes above ~1N4148 forward bias
- Charges C48 through R79 with τ = 1MΩ × 10µF = **10 seconds** (very slow, predictable timing)

---

### Stage 3: Reverse Polarity Protection

| Component | Value | Function | Notes |
|---|---|---|---|
| **D14** | SMF3.3A (TVS) | Reverse polarity blocking | Uni-directional; VR = 3.3V, VBR = 3.4–4.3V |
| **R79** | 1MΩ, 1/4W | Bleed resistor for capacitor discharge | Provides predictable RC timing; high-Z input friendly |

**Performance:**
- Blocks reverse polarity (24V AC applied backwards)
- Discharges C48 and C47 with τ = **10 seconds** (stable, predictable)
- Minimal steady-state current: <1µA leakage @ 3.3V

---

### Stage 4: GPIO Overvoltage Clamping & Filtering

| Component | Value | Function | Notes |
|---|---|---|---|
| **R (GPIO limiting)** | 2.2kΩ, 1/4W | Current limiting to GPIO | Protects pin from inrush current |
| **BZT52C3V3** | Zener ≥400mW | Clamps voltage to exactly 3.3V | Precise regulation vs wide-range TVS |
| **C47** | 100nF, 16V ceramic | Final GPIO high-frequency filter | τ = 1MΩ × 100nF = 100ms |

**Performance for 24V AC peak input:**
- Current through 2.2kΩ at 24V: (24V − 3.3V) / 2.2kΩ = **9.4mA** (safe)
- Power in Zener: 20.7V × 9.4mA ≈ **195mW** (within 400mW rating)
- **GPIO voltage clamped to 3.3V ± 0.2V** (Zener tolerance)

---

### Stage 5: Phantom Triac Load Network

| Component | Value | Function | Notes |
|---|---|---|---|
| **R (Load)** | 4.7kΩ, 0.5W (RC2010FK-074K7L) | Triac output load resistor | Provides DC load; prevents floating high when triac is off |
| **C (Load)** | 2.2µF, 16V | AC impedance matching | Xc = 1.2kΩ at 60Hz; balanced AC signal coupling |

**Background:**
Thermostat triac outputs can float capacitively high when unloaded, causing false GPIO activation (known issue: Y input activating unexpectedly due to floating voltage). The phantom load network prevents this by:

1. **Providing a DC load path** when the triac is not actively sinking current
2. **Pulling the signal toward ground** through the resistor
3. **AC impedance matching** with the capacitor (Xc = 560Ω at 60Hz)
4. **Establishing predictable impedance** for signal coupling

**Performance for 24V AC:**
- Load current (triac off): 24V / 4.7kΩ = **5.1mA continuous**
- Power dissipation: 24V × 5.1mA = **122mW**
- Power rating: RC2010FK = **0.5W (500mW)** ✓ **24% utilization** (safe margin)
- **Impedance at 60Hz:** Xc = 1/(2π × 60 × 2.2µF) ≈ **1.2kΩ** (capacitive reactance)
- **Total impedance:** Z = √(4700² + 1200²) ≈ **4,850Ω** (balanced loading)

---

## Design Rationale

### Two-Stage Decoupling (C46 + C48)

The 24V AC input contains 60Hz fundamental and harmonics. Two capacitors in series with protection stages provide:
1. **Early attenuation** at the input (C46) before signal conditioning
2. **Final buffering** before GPIO (C48) after protection diodes
3. **Predictable charge/discharge timing** via the 1MΩ resistor

### 1MΩ Bleed Resistor (R79)

ESP32 GPIO inputs are high-impedance (~10MΩ). Without a bleed path:
- Capacitors would hold charge indefinitely
- Timing would be unpredictable and temperature-dependent

The 1MΩ resistor provides:
- Controlled discharge path: τ = 1MΩ × ~10µF ≈ **10 seconds**
- Consistent RC behavior across temperature/tolerance variations
- Negligible DC power: at 3.3V, I = 3.3V / 1MΩ = **3.3µA**

### Current-Limited Zener Clamp (R + BZT52C3V3)

A high-voltage TVS (SMF24/SMF30) would clamp at ~20–30V, still above ESP32 safe voltage. Instead:

- **2.2kΩ resistor** limits inrush: (24V − 3.3V) / 2.2kΩ = 9.4mA (manageable)
- **BZT52C3V3 Zener** clamps at precise **3.3V** (matches GPIO max)
- **Result:** GPIO pin safe from all overvoltage conditions

---

## Protection Features

| Fault Condition | Mechanism | Outcome |
|---|---|---|
| **Reverse 24V AC** | D14 reverse polarity blocking | Blocks reverse current; GPIO protected |
| **24V AC overshoot** | 2.2kΩ + BZT52C3V3 clamping | GPIO held at 3.3V; Zener dissipates power |
| **60Hz AC ripple** | C46 + C48 RC filtering | Attenuated to sub-mV levels |
| **Transient spikes** | D15 (1N4148) fast diode | Clamps to ~0.7V forward bias |
| **DC short to ground** | R5 (33kΩ) current limiting | Limits fault current to <1mA |
| **High-frequency noise** | C47 (100nF) GPIO filter | Attenuates EMI above ~1kHz |

---

## PCB Layout Recommendations

1. **C46 and C48 placement:**
   - Mount C46 close to R5 input junction
   - Mount C48 close to D14 output junction
   - Keep traces short to minimize inductance

2. **GND connections:**
   - All capacitor GND pins tie to main GND plane
   - Use multiple vias for GND return

3. **GPIO pin:**
   - BZT52C3V3 cathode directly to ESP32 pin (minimal trace)
   - C47 cathode to GND plane near GPIO

4. **Thermal:**
   - During 24V overvoltage fault, BZT52C3V3 dissipates ~195mW
   - Ensure adequate copper area around Zener (no thermal island)
   - SMD Zener will reach ~80°C but is rated to 150°C

---

## Bill of Materials (Per Input)

| Qty | Reference | Value | Package | LCSC Part # | Notes |
|-----|---|---|---|---|---|
| 1 | R5 | 33kΩ 1/4W | 0603 | C22869 | Input current limiting |
| 1 | C46 | 10µF 50V | 0805 | C45783 | Stage 1 decoupling |
| 1 | D15 | 1N4148W-7-F | SOD-123FL | C1840 | Transient protection |
| 1 | C48 | 10µF 50V | 0805 | C45783 | Stage 2 decoupling |
| 1 | D17 | SMF5.0A | SOD-123FL | C509127 | Reverse polarity TVS |
| 1 | R80 | 2.2kΩ 1/4W | 0603 | C22838 | Zener current limiting |
| 1 | D16 | BZT52C3V3 | SOD-123 | C160222 | Overvoltage clamp (3.3V Zener) |
| 1 | R79 | 1MΩ 1/4W | 0603 | C25791 | Bleed resistor (GPIO discharge) |
| 1 | C47 | 100nF 16V | 0603 | C57112 | GPIO high-frequency filter |
| 1 | R (Load) | 4.7kΩ 0.5W | 2010 | C513572 | Phantom triac load resistor (RC2010FK) |
| 1 | C (Load) | 2.2µF 16V | 0805 | C45784 | Phantom triac load capacitor (Xc = 1.2kΩ @ 60Hz) |

**Total per input:** ~$0.25 in component cost (BOM estimates from LCSC)

---

## Testing & Verification

### Functional Test (DC)
1. Apply **+24V DC** to input → GPIO reads **HIGH**
2. Apply **0V (GND)** → GPIO reads **LOW**
3. Remove input (floating) → GPIO reads **HIGH** (pull-up via R79)
4. Verify no GPIO overvoltage with multimeter (should see ~3.3V)

### Reverse Polarity Test (DC)
1. Reverse input polarity: **−24V** to input, **+24V to GND**
2. GPIO should remain **LOW** (D14 blocks reverse current)
3. No damage or current draw observed

### AC Functional Test (24V AC, 60Hz)
1. Apply **24V AC source** to input
2. GPIO toggles at 60Hz (rectified waveform)
3. Measure GPIO voltage with oscilloscope: **0V to +3.3V peak** (no overshoot)
4. Verify clamping voltage with AC signal applied (BZT52C3V3 should be conducting)

### Thermal Test
1. Apply continuous 24V AC overvoltage to input
2. Measure BZT52C3V3 temperature with IR thermometer
3. Should stabilize <80°C under nominal fault conditions

---

## Design Trade-offs

| Trade-off | Choice | Reason |
|---|---|---|
| **Single vs. two-stage decoupling** | Two-stage (C46 + C48) | Better 60Hz attenuation; predictable timing |
| **Zener vs. high-voltage TVS** | BZT52C3V3 Zener | Precise 3.3V clamp; no overvoltage to GPIO |
| **Bleed resistor value** | 1MΩ | High-Z friendly; ~10s discharge time; 3.3µA steady-state |
| **Series resistor before Zener** | 2.2kΩ | Limits fault current to 9.4mA; 195mW dissipation acceptable |

---

## Known Limitations

1. **Power dissipation:** Under sustained 24V overvoltage (DC short), the 2.2kΩ resistor and Zener dissipate ~195mW each. This is safe for brief faults but will damage components under prolonged overcurrent (>seconds). **Recommendation:** Use input validation logic to detect and alert on persistent faults.

2. **Temperature drift:** BZT52C3V3 Zener voltage drifts ~0.1%/°C. Under worst-case temperature (−55°C to +150°C), clamp voltage can vary ±0.2V. This is within ESP32 GPIO margin.

3. **AC ripple residual:** At 60Hz input, even with two 10µF caps, some ripple appears on the GPIO after rectification. Software debounce (currently 2s) masks this.

---

## References

- **BZT52C3V3 Zener Datasheet:** Common generic Zener, available from LCSC (C160222)
- **SMF3.3A TVS Datasheet:** See `docs/TVS-SMF3-3-1103.pdf`
- **1N4148W-7-F Diode:** Fast switching diode, 75V reverse rating
- **ESP32-S3 GPIO Specifications:** 3.3V max input, internal ESD protection

---

## Revision History

| Date | Version | Author | Change |
|---|---|---|---|
| 2026-03-23 | 1.1 | Design | Added phantom triac load network (Stage 5) to prevent floating high; updated BOM with LCSC part numbers |
| 2026-03-22 | 1.0 | Design | Initial circuit finalization for all 4 inputs (LPS, DFT, Y, O) with multi-stage protection |

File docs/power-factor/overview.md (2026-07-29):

# Power Factor Monitoring

## Overview

Power factor (PF) measurement for compressor and fan motors using simultaneous
voltage and current sampling. Replaces the I2C ADS1115 daughter board with an
on-board SPI ADC (ADS131M04) that provides true RMS current, real power,
apparent power, reactive power, and power factor — all computed from raw
waveform samples.

## Why Power Factor

- **Motor health**: A dropping PF on the compressor indicates winding
  degradation, bearing problems, or mechanical loading issues before they
  become catastrophic failures
- **Locked rotor detection**: A severely lagging PF during startup confirms a
  stalled motor versus normal inrush
- **Efficiency monitoring**: Real power (W) vs apparent power (VA) shows how
  much energy is wasted as reactive power
- **Diagnostic data**: PF changes correlate with refrigerant charge issues,
  iced coils, and airflow restrictions

## Architecture

### ADC: ADS131M04

| Parameter | Value |
|---|---|
| Manufacturer | Texas Instruments |
| Channels | 4 independent, **simultaneous-sampling** |
| Resolution | 24-bit delta-sigma |
| Sample rate | Up to 32 kSPS per channel |
| Interface | SPI (up to 25 MHz) |
| Input mode | Differential per channel |
| PGA | 1x–128x internal programmable gain |
| Reference | 1.2V internal |
| DRDY | Active-low data-ready interrupt |
| Package | TQFP-32 or QFN-24 |
| LCSC | C2904283 (TQFP-32) |

**Why simultaneous sampling matters:** Multiplexed ADCs (like the ADS1115)
sample channels sequentially. At 60Hz, even a 1ms delay between voltage and
current samples introduces ~21° of phase error — enough to make PF
measurements meaningless. The ADS131M04 samples all 4 channels at the exact
same instant, eliminating inter-channel phase error entirely.

### Channel Allocation

| Channel | Differential Pair | Function |
|---|---|---|
| Ch1 | AIN1P / AIN1N | Compressor CT clamp (SCT-013-030, 30A range) |
| Ch2 | AIN2P / AIN2N | Fan CT clamp (SCT-013-030, 30A range) |
| Ch3 | AIN3P / AIN3N | 24VAC voltage reference (resistor divider) |
| Ch4 | AIN4P / AIN4N | Crankcase heater CT clamp (SCT-013-005, 5A range) |

**Crankcase heater monitoring (Ch4):** Scroll compressor heat pumps have a
resistive crankcase heater (typically 40–80W at 240V, drawing 0.17–0.33A)
that keeps compressor oil warm during off-cycles to prevent liquid refrigerant
migration. A failed heater leads to oil dilution and compressor slugging on
cold-weather startup — potentially destroying scroll valves.

The SCT-013-030 (30A range) has poor resolution at sub-amp levels. Use an
**SCT-013-005** (5A range, 1V output) for the heater channel. Same 3.5mm TRS
jack, same circuit. Set ADS131M04 PGA to 4x or 8x for optimal sensitivity.

**Heater diagnostics:**
- Heater ON + compressor OFF = normal (oil warming)
- Heater OFF + compressor OFF = **failed heater** — log warning/fault
- Heater ON + compressor ON = wasted energy (some units don't switch it off)
- Gradual current drop over time = element degradation

### GPIO Pin Assignment (ESP32-S3)

Dedicated SPI bus, separate from the SD card SPI (GPIO 10–13).

| GPIO | Function | ADS131M04 Pin |
|---|---|---|
| 1 | SPI SCLK | SCLK |
| 2 | SPI MOSI (DIN) | DIN |
| 42 | SPI MISO (DOUT) | DOUT |
| 45 | SPI CS | /CS |
| 46 | DRDY interrupt | /DRDY |

**Voltage zero-crossing (optional, if using optocoupler instead of Ch3):**

| GPIO | Function |
|---|---|
| 47 | Voltage ZC from SN74HC14DR channel 5Y |

Using the lowest available GPIOs first. GPIO 47 is only needed if the voltage
zero-crossing is handled by the existing optocoupler + Schmitt trigger circuit
instead of ADC channel 3. With the ADS131M04 sampling voltage on Ch3, GPIO 47
is not required — zero crossings are detected from the sampled waveform.

### Existing GPIO Map (for reference)

| GPIO | Current Function |
|---|---|
| 3 | AUX output relay |
| 4 | FAN output relay |
| 5 | CNT output relay |
| 6 | W output relay |
| 7 | RV output relay |
| 8 | I2C SDA (OLED, ADS1115) |
| 9 | I2C SCL |
| 10–13 | SD card SPI (CS, MOSI, MISO, CLK) |
| 14 | CAN RX (TWAI) |
| 15 | LPS input |
| 16 | DFT input |
| 17 | Y input |
| 18 | O input |
| 21 | OneWire bus |
| 38 | CAN TX (TWAI) |
| 39–41 | Unused (formerly MAX6675 SPI CLK/CS/DO) |

**Unavailable:** 0 (boot), 19–20 (USB), 26–37 (flash/PSRAM), 43–44 (Serial).

**Remaining free after PF addition:** GPIO 47, 48 (or 48 only if using
optocoupler ZC on 47).

## CT Clamp Interface

Universal 3.5mm TRS jacks supporting both voltage-output CTs (SCT-013-005/
010/030 with internal burden) and current-output CTs (SCT-013-000 with
external burden resistor). Each jack has a 2-pin 2.54mm female header across
tip-to-ring for socketed burden resistor placement — leave empty for
voltage-output CTs, insert appropriate through-hole resistor (1% or better)
for current-output CTs. No soldering required for burden changes.

### Per-Channel Circuit

```
              R_burden (2.54mm header socket, empty for voltage-output CTs)
CT tip ──┬──────[■ ■]────────────┬── CT ring
         │                        │
        10μF                     10μF
         │                        │
     10kΩ ── Vbias            10kΩ ── Vbias
         │                        │
       TVS ── GND              TVS ── GND
         │                        │
       AINxP                   AINxN
```

  TVS = PESD3V3L2BT (dual bidirectional, one per channel)

- **Vbias**: 1.65V from resistor divider (2× 1kΩ from 3.3V) + 100nF + 10μF
  filter caps. Provides DC operating point for the AC-coupled CT signal.
- **10kΩ bias resistors**: On both differential inputs, sets DC operating
  point at Vbias (1.65V)
- **10μF coupling caps**: AC-couple on **both** differential inputs for
  symmetric DC blocking. At 60Hz with 10kΩ bias, high-pass cutoff is 1.6Hz
  — transparent to the 60Hz signal
- **R_burden**: Optional external burden resistor for current-output CTs
  (SCT-013-000, 2000:1 turns ratio). R = V_target × 2000 / I_max. Use 1%
  tolerance or better (standard 1/4W through-hole axial, bent to 2.54mm pin
  spacing). See burden table in `schematic-notes.md` for common values.
- **PGA setting**: Use 1x for full range, 2x or 4x for higher sensitivity on
  low-current loads (fan motor, crankcase heater)
- **TVS protection**: PESD3V3L2BT (Nexperia, C55440) on each ADC input to
  GND. Clamps transients from motor inrush, hot-plugging, and ESD

### CT Clamp Compatibility

| CT Model | Type | Output | R_burden | Use Case |
|---|---|---|---|---|
| SCT-013-030 | Voltage | 1V @ 30A | none | Compressor (default) |
| SCT-013-010 | Voltage | 1V @ 10A | none | Small compressor |
| SCT-013-005 | Voltage | 1V @ 5A | none | Fan, crankcase heater |
| SCT-013-000 | Current | 50mA @ 100A | 66Ω → 30A range | Compressor (high precision) |
| SCT-013-000 | Current | 50mA @ 100A | 400Ω → 5A range | Fan (high precision) |
| SCT-013-000 | Current | 50mA @ 100A | 2kΩ → 1A range | Crankcase heater (high precision) |

Software CT ratio is configured per-channel via the config page dropdown.
When using SCT-013-000 with burden, set the dropdown to match the effective
range (e.g., 66Ω burden = 30A effective → select SCT-013-030).

### Voltage Reference Circuit (Ch3)

24VAC from the furnace transformer, divided down to ±1V range for ADC input.
COM is tied directly to digital GND (see power supply design note below),
so no isolation is needed.

```
24VAC ── 33kΩ ──┬── TVS_A ── GND
                │
              10μF (DC blocking)
                │
              AIN3P
                │
              100nF (HF filter)
                │
              AIN3N
                │
               1kΩ
                │
              TVS_B ── GND
                │
COM/GND ────────┘
```

TVS = PESD3V3L2BT (dual bidirectional, same as CT channels)

- Divider ratio: 1k / (33k + 1k) ≈ 1:34
- 24V RMS → 0.71V RMS at ADC input (1.0V peak) — within ±1.2V PGA=1x range
- COM = digital GND — single ground domain, no isolation required
- 10μF coupling cap blocks DC offset from transformer asymmetric loading
  (high-pass cutoff ~16Hz with 1kΩ — transparent to 60Hz)
- 100nF across 1kΩ for HF noise rejection
- TVS clamps transients from transformer inrush and line surges
- **Phase accuracy**: Resistive divider introduces no phase shift (unlike a
  transformer-based reference). The voltage sample is phase-true to the
  actual line voltage

### Power Supply Design Note

The main board power supply uses a **half-wave rectifier** (single diode)
from 24VAC, with COM tied directly to digital GND. This creates a single
ground domain across the entire system:

- **No isolation needed** for voltage reference (Ch3) — COM = GND
- **No isolated ground** required for inter-board digital buses (CAN, I2C)
- **Simplified analog front end** — all ADC channels share the same ground
- **Simplified 24VAC inputs** — optocouplers (AT3H7C) and Schmitt triggers
  (SN74HC14DR) replaced by passive divider + diode + TVS + filter cap
  directly into ESP32 GPIO. See `schematic-notes.md` for circuit detail

Tradeoff vs full-wave bridge (MB10S): half-wave produces ~2× ripple on the
input filter cap (16.7ms hold-up vs 8.3ms at 60Hz). Mitigated by using a
larger input filter cap (1000μF 50V vs 470μF). 50V rating is sufficient —
SMAJ36CA TVS clamps transients to ~58V max, and the upstream fuse limits
sustained fault current. The LGS5145 buck converter's wide input range
handles the additional ripple without issue.

## Software Design

### Sampling

The ADS131M04 DRDY pin triggers an ISR on GPIO 46. The ISR reads all 4
channels via SPI in a single transaction (~4μs at 25MHz SPI clock). Samples
are stored in a circular buffer sized for one complete 60Hz cycle.

**Target sample rate**: 4 kSPS (4000 samples/sec per channel)
- 66.7 samples per 60Hz cycle — sufficient for accurate RMS and PF
- 250μs between samples
- DRDY ISR + SPI read takes ~10μs — negligible CPU overhead

### Computation (per cycle)

Performed in a TaskScheduler task (e.g., every 500ms = 30 complete cycles
averaged):

```
V_rms = sqrt(mean(v[n]²))
I_rms = sqrt(mean(i[n]²))
P_real = mean(v[n] * i[n])          // instantaneous power, averaged
P_apparent = V_rms * I_rms
P_reactive = sqrt(P_apparent² - P_real²)
PF = P_real / P_apparent
```

**No zero-crossing detection needed.** With simultaneous V and I samples,
true power is computed directly from the instantaneous product V×I averaged
over complete cycles. PF falls out of the ratio of real to apparent power.
This is more accurate than zero-crossing phase measurement, which only works
for pure sinusoidal waveforms.

### Data Output

New fields in `/state` JSON and MQTT `goodman/state` payload:

```json
{
  "compressorPF": 0.87,
  "compressorWatts": 1850,
  "compressorVA": 2126,
  "compressorVAR": 1048,
  "fanPF": 0.72,
  "fanWatts": 285,
  "fanVA": 396,
  "fanVAR": 275,
  "voltageRMS": 24.1,
  "crankcaseHeaterAmps": 0.29,
  "crankcaseHeaterOn": true
}
```

Dashboard: Power card with PF gauge, real/apparent/reactive power display.
TempHistory: Additional chart sensors for PF and power tracking over time.

### Existing Code Changes

| File | Change |
|---|---|
| `src/CurrentSensor.cpp` | Replace `readRMS()` ADS1115 logic with ADS131M04 SPI reads. RMS computed from sample buffer instead of per-call ADC reads |
| `include/CurrentSensor.h` | Add PF, watts, VA, VAR members and getters. Remove `Adafruit_ADS1X15.h` dependency |
| `src/main.cpp` | Initialize dedicated SPI bus on GPIO 1/2/42/45. Configure ADS131M04 registers. DRDY ISR on GPIO 46. Remove ADS1115 init |
| `src/WebHandler.cpp` | Add PF/power fields to `/state` JSON |
| `src/HttpsServer.cpp` | Mirror PF/power fields in HTTPS `/state` handler |
| `src/MQTTHandler.cpp` | Add PF/power fields to `publishState()` |
| `data/www/dashboard.html` | Power card with PF display, power charts |
| `platformio.ini` | Remove `Adafruit ADS1X15` lib dep, add ADS131M04 driver (or custom) |

### ADS131M04 vs ADS1115 Comparison

| Feature | ADS1115 (current) | ADS131M04 (new) |
|---|---|---|
| Channels | 2 differential | 4 differential |
| Sampling | Multiplexed | **Simultaneous** |
| Resolution | 16-bit | 24-bit |
| Max SPS | 860 | 32,000 |
| Interface | I2C (400kHz) | SPI (25MHz) |
| PGA | 2/3x–16x | 1x–128x |
| Thread safety | I2C bus shared | Dedicated SPI bus |
| Level shifter | Required (3.3V↔5V) | Not needed (3.3V native) |
| Board | Separate daughter PCB | Integrated on main board |
| Power factor | Not possible | Yes (simultaneous V×I) |

## Bill of Materials (additions to HP board)

| Ref | Part | Package | LCSC | Qty | Notes |
|-----|---|---|---|-----|---|
| U_ADC | ADS131M04IRSMR | TQFP-32 | C2904283 | 1 | 4-ch simultaneous ADC |
| R_bias1–6 | 10kΩ | 0402 | — | 6 | CT clamp bias resistors (2 per channel × 3 CT channels) |
| R_divH | 1kΩ (2×) | 0402 | — | 2 | Vbias 1.65V divider (from 3.3V) |
| R_vdivH | 33kΩ | 0402 | — | 1 | Voltage divider high side |
| R_vdivL | 1kΩ | 0402 | — | 1 | Voltage divider low side |
| C_bias | 100nF + 10μF | 0402/0805 | — | 2 | Vbias filter |
| C_couple | 10μF | 0805 | — | 7 | AC coupling / DC blocking (2 per CT channel × 3 + 1 voltage Ch3) |
| D_tvs1–4 | PESD3V3L2BT,215 | SOT-23 | C55440 | 4 | ADC input TVS protection (3 CT + 1 voltage) |
| C_vfilt | 100nF | 0402 | — | 1 | Voltage input HF filter |
| H_burd1–3 | 2-pin 2.54mm female | THT | — | 3 | CT burden resistor socket (empty for voltage-output CTs) |
| C_bypass | 100nF + 10μF | 0402/0805 | — | 2 | ADC power supply bypass |
| J_CT1 | 3.5mm TRS jack | — | — | 1 | Compressor CT (universal) |
| J_CT2 | 3.5mm TRS jack | — | — | 1 | Fan CT (universal) |
| J_CT3 | 3.5mm TRS jack | — | — | 1 | Crankcase heater CT (universal) |

All three CT jacks are universal — supporting both voltage-output CTs
(SCT-013-005/010/030, burden header empty) and current-output CTs
(SCT-013-000, burden resistor inserted into header). Each jack has a
2-pin 2.54mm female header across tip-to-ring. For SCT-013-000, insert
a standard 1/4W through-hole axial resistor (1% or better tolerance)
bent to 2.54mm pin spacing into the socket. Default: empty (voltage-output
CTs). See CT compatibility table above and burden table in
`schematic-notes.md` for values when using SCT-013-000.

## References

- [ADS131M04 datasheet](https://www.ti.com/lit/ds/symlink/ads131m04.pdf)
- [TI Power Measurement app note (SBAA336)](https://www.ti.com/lit/an/sbaa336/sbaa336.pdf)
- [SCT-013-030 CT clamp datasheet](https://en.yhdc.com/product/SCT013-401.html)
- Existing current sensing design: `docs/current-sensing.md`

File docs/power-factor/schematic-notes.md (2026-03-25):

# Power Factor Board Integration — Schematic Notes

## Context

These notes document the integration of power factor monitoring into the
Goodman HP Controller board revision, replacing the separate I2C ADS1115
daughter board with an on-board ADS131M04 SPI ADC.

## Triac Phantom Signal Fix (R79–R86)

The v2.0 furnace/HP controller board uses KMOC3021S triac optocouplers for
24VAC output switching. Triac off-state leakage can hold downstream relay
coils partially energized ("phantom" signals), causing false Y/O inputs to the
HP controller.

**Root cause observed 2026-03-22:** Thermostat went idle at 11:31 CDT but the
HP controller's Y input stayed active for 56 additional minutes. Compressor
ran with no indoor airflow, suction temp climbed to 130°F+. Confirmed via
Home Assistant thermostat history vs controller logs.

**Fix per channel (R79–R86 on furnace board, similar on HP board):**

```
Triac output ──┬── 4.7kΩ ── COM     (resistive bleeder, 123mW @ 24VAC)
               └── 470nF X2 ── COM  (capacitive bleeder, ~0W real dissipation)
```

- **4.7kΩ resistor**: Handles DC leakage path. 123mW fits 1206 or 2512
  package with margin — no thermal issues unlike the original 2kΩ (288mW)
  that desoldered SMD parts off the board.
- **470nF X2 cap**: Handles AC sneak paths. ~4.3mA reactive current at 60Hz,
  near-zero real power. X2 safety rating for across-the-line AC use.
- Combined impedance at 60Hz: ~560Ω — provides strong loading to prevent
  triac leakage from energizing relay coils.

## Daughter Board Architecture (Power Factor Module)

The power factor monitoring circuit is implemented as a **separate daughter board**
connected to the main board via two isolated headers. This provides optimal
analog/digital separation and noise isolation.

### Board Separation Strategy

**Main Board** (noisy digital domain)
- ESP32-S3 (WiFi, SPI switching)
- Relay triac drivers (24VAC switching)
- Buck converter (1MHz switching)

**Daughter Board** (clean analog domain)
- ADS131M04 ADC
- CT clamp conditioning (3× PJ-3200A-3A jacks)
- Voltage reference divider (24VAC)
- Vbias generation (1.65V divider)
- SCT-013-000 burden resistor sockets (3× socketed, field-swappable)

**Connection:** Two isolated headers carrying only power and SPI signals

### Header 1: Analog Power & Signals

**Purpose:** Power and analog signal conditioning — isolated power domain

```
Connector: [2×3 pinheader or equivalent]

Pin 1: 24VAC (from main board transformer secondary)
Pin 2: 24VAC (return, same as Pin 1 — two conductors for current distribution)
Pin 3: GND (AGND — analog ground, isolated return)
Pin 4: CT_CH1_TIP (from PJ-3200A-3A Jack 1, tip contact)
Pin 5: CT_CH1_RNG (from PJ-3200A-3A Jack 1, ring contact)
Pin 6: CT_CH2_TIP (from PJ-3200A-3A Jack 2, tip contact)
Pin 7: CT_CH2_RNG (from PJ-3200A-3A Jack 2, ring contact)
Pin 8: CT_CH4_TIP (from PJ-3200A-3A Jack 3, tip contact)
Pin 9: CT_CH4_RNG (from PJ-3200A-3A Jack 3, ring contact)
```

**Alternative (lower pin count with internal jacks on daughter board):**
```
If jacks are mounted directly on daughter board (recommended):

Pin 1: 24VAC
Pin 2: 24VAC (return)
Pin 3: AGND (isolated return)
Pin 4: Burden Socket Pin A (Ch1) — optional, if burden headers not on daughter
Pin 5: Burden Socket Pin B (Ch1) — optional
...
```

**Burden Resistor Sockets:**
- Three 2-pin 2.54mm female headers (one per CT channel)
- Mounted directly on daughter board
- Allow field-swappable 1% precision resistors
- No connector needed — socketed resistors stay on daughter board

**Notes:**
- 24VAC has two paths for current distribution (lower impedance)
- AGND is isolated — does NOT connect to main board GND at this header
- CT signal conditioning (filtering, TVS protection) happens on daughter board
- This header carries only low-frequency signals (60Hz AC, <1kHz)

### Header 2: SPI Digital Communication

**Purpose:** Digital SPI bus only — isolated digital return path

```
Connector: [2×3 pinheader or equivalent]

Pin 1: 3.3V VDD (power for ADC DVDD and pull-up resistors)
Pin 2: SCLK (from ESP32 GPIO 1)
Pin 3: DIN / MOSI (from ESP32 GPIO 2)
Pin 4: /CS (from ESP32 GPIO 45)
Pin 5: /DRDY (to ESP32 GPIO 46, falling-edge interrupt)
Pin 6: DGND (isolated digital ground — separate return path)
```

**Notes:**
- DGND at this header is **NOT connected to main board DGND**
- Provides isolated return path for SPI currents
- Star grounding on daughter board merges AGND and DGND under ADS131M04
- All SPI pull-up/pull-down resistors on daughter board
- Traces from this header to ADC are short and isolated

### Isolation Benefit

By using two separate headers:

1. **Header 1 (Power):**
   - Carries 24VAC and isolated AGND
   - No digital switching noise injected
   - Clean analog power domain

2. **Header 2 (SPI):**
   - Carries only digital SPI signals (low current)
   - Separate DGND return path isolated from main board digital noise
   - SCLK switching confined to daughter board local loops

3. **Isolation between headers:**
   - Single star point connection under ADS131M04
   - Minimizes coupling between noisy digital and sensitive analog

### PCB Layout on Daughter Board

- **Header 1 location:** Near CT jack connectors and voltage reference circuit
- **Header 2 location:** Opposite corner from header 1 (maximizes separation)
- **AGND island:** Extends from header 1 to ADC and all analog circuits
- **DGND return:** Isolated star connection under ADC from header 2
- **SPI traces:** Route away from analog signal region (minimum 30mm)

### Mechanical Mounting

Suggested mounting scheme:
- Two mounting posts (one near each header) to keep daughter board parallel
- 2-5mm standoffs to prevent shorts
- Keying notches on headers to prevent misconnection

### Testing & Debug

With isolated headers:
1. Daughter board can be tested standalone (apply 24VAC + 3.3V to headers)
2. Main board can be tested independently (no analog circuits affected)
3. If ADC noise issues arise: daughter board can be replaced or reworked without disturbing main board
4. Easier to isolate EMI sources (24VAC switching vs ESP32 noise)

---

## SPI Bus Wiring Summary (Main Board)

```
ESP32-S3              H1 Header (Daughter Board)
────────              ──────────────────────────
GPIO 1  ────────────→ Pin 5: SCLK
GPIO 2  ────────────→ Pin 4: DIN  (MOSI)
GPIO 42 ←──────────── Pin 6: DOUT (MISO)
GPIO 45 ────────────→ Pin 3: /CS
GPIO 46 ←──────────── Pin 2: /DRDY (data ready interrupt)

3.3V    ────────────→ Pin 1: VDD
GND     ────────────→ Pin 7: DGND (isolated digital return)
```

**Notes:**
- H1 is a 7-pin isolated SPI header on daughter board
- DGND return at pin 7 is isolated from main board GND
- No analog signals cross the bridge (only SPI + isolated DGND)
- SCLK speed: 10–25 MHz (ADS131M04 supports up to 25 MHz)
- /DRDY interrupt: Configure GPIO 46 as falling-edge (data ready)
- DOUT (MISO): Configure GPIO 42 as SPI input for serial data readout

## VBIAS Reference Generation

The VBIAS reference is generated from the **ADS131M04's internal 1.2V voltage reference**
using an OP07 precision op-amp configured as a non-inverting amplifier with gain = 1.375.

**Circuit topology:**

```
ADS131M04 CAP pin (1.2V internal ref)
    │
    ├─── 220nF ── AGND  (required per ADS131M04 datasheet)
    │
    └─── [OP07 pin 3 (+input)]
         │
         │     ┌────── Rf: 15kΩ ──────┐
         │     │                      │
    ┌────┤+3V  OP07      [Out] ────┬──┴──► VBIAS = 1.65V
    │    │     (pins 8,4)  │       │
    │    │                 │       ├─ C (10µF) ── AGND
    │    ├─ Rg: 40kΩ ─ AGND
    │    │
    │    └─ Ref: AGND
    │
3.3V ────┴──► OP07 pin 8 (V+ supply)
        100nF bypass cap ── AGND

Gain = 1 + Rf/Rg = 1 + 15k/40k = 1.375
VBIAS_out = 1.2V × 1.375 = 1.65V
```

**Component specifications:**

| Component | Value | Function |
|---|---|---|
| U_ref | OP07 | Ultra-low offset op-amp (Vos ±0.3mV) |
| Rf | 15kΩ 1% metal film | Feedback resistor for gain setting |
| Rg | 40kΩ 1% metal film | Ground reference resistor |
| C_bypass (OP07 pin 8) | 100nF ceramic 0603 | Power supply bypass |
| C_out | 10µF ceramic 0805 | Output load capacitor |
| CAP decoupling | 220nF ceramic 0603 | Required by ADS131M04 datasheet |

**Advantages over external voltage divider:**

1. **Temperature matching:** VBIAS inherits the ADC's internal reference temperature drift
   (20 ppm/°C). Both drift together → no relative error.

2. **Superior accuracy:** ±0.1% internal reference vs ±1-2% supply-dependent divider

3. **Ultra-low offset:** OP07 Vos ±0.3mV ensures accurate 1.65V ± 3mV output

4. **Low noise:** OP07 noise floor (25 nV/√Hz) provides clean VBIAS to all bias networks

5. **No supply noise:** Reference is internal to ADC, not coupled through 3.3V rail

6. **Full ADC range utilization:** ±1.2V input range fully exploited (vs ±0.6V if using 1.2V directly)

**Power supply requirements:**

- OP07 single-supply mode: +3.3V (pin 8) and AGND (pin 4)
- Must add 100nF bypass capacitor on +3.3V near pin 8
- OP07 can swing output close to rails (within ~0.2V of supplies)
- Output swing: 0V to 3.3V, sufficient for 1.65V VBIAS

## Voltage Reference Input (Ch3)

The 24VAC from the furnace transformer secondary is used as the phase-true voltage reference
for power factor angle measurement. This signal is attenuated to match the ADC input range via
a 1:34 voltage divider and TVS protection.

```
24VAC ── 33kΩ ──┬── TVS_A ── GND
                │
              10μF (DC blocking)
                │
              AIN3P
                │
              100nF (HF filter)
                │
              AIN3N
                │
               1kΩ
                │
              TVS_B ── GND
                │
COM/GND ────────┘
```

TVS = PESD3V3L2BT (dual bidirectional, same as CT channels)

- Ratio: 1:34 → 24V RMS becomes 0.71V RMS (1.0V peak)
- Within ADS131M04 ±1.2V input range at PGA=1x
- COM = digital GND — single ground domain, no isolation required
- 10μF coupling cap blocks DC offset from transformer asymmetric loading
  (high-pass cutoff ~16Hz with 1kΩ — transparent to 60Hz)
- 100nF across 1kΩ for HF noise rejection
- TVS clamps transients from transformer inrush and line surges
- **Phase accuracy**: Resistive divider introduces no phase shift. The voltage sample is
  phase-true to the actual line voltage at the AC unit input.

### Power Supply: Half-Wave Rectifier Design

The main board uses a half-wave rectifier (single diode from 24VAC) instead
of a full-wave bridge, tying COM directly to digital GND. This creates a
single ground domain across the entire system, eliminating the need for
galvanic isolation on the voltage reference and inter-board digital buses
(CAN, I2C).

Tradeoff: ~2× ripple vs full-wave bridge (16.7ms hold-up at 60Hz vs 8.3ms).
Mitigated by using 1000μF 50V input filter cap (vs 470μF 63V). 50V rating
is sufficient — SMAJ36CA TVS upstream clamps transients to ~58V max and the
fuse limits sustained fault current. The LGS5145 buck converter's wide input
range handles the additional ripple without issue.

## CT Clamp Interface (Ch1, Ch2, Ch4)

Three universal 3.5mm TRS jacks supporting both voltage-output CTs
(SCT-013-005/010/030) and current-output CTs (SCT-013-000). Each jack has
a 2-pin 2.54mm female header across tip-to-ring for socketed burden resistor
placement.

- **Voltage-output CT** (e.g., SCT-013-005/030): Leave burden header **empty**.
  CT has internal burden; outputs voltage directly.
- **Current-output CT** (SCT-013-000, 2000:1 ratio, 50mA @ 100A): Insert a
  through-hole resistor (1% tolerance or better) bent into a 2-pin male header
  into the burden socket. Output voltage = I_secondary × R_burden.

The socketed design allows field-swapping burden values without soldering —
just pull the old resistor and insert a new one to change the effective
measurement range.

### Universal Jack Circuit

```
              R_burden (2.54mm header socket, empty for voltage-output CTs)
CT tip ──┬──────[■ ■]────────────┬── CT ring
         │                        │
        10μF                     10μF
         │                        │
     10kΩ ── Vbias            10kΩ ── Vbias
         │                        │
       TVS_A                    TVS_B     ← PESD3V3L2BT (dual bidir, SOT-23)
         │                        │
       AINxP                   AINxN
```

### Burden Resistor Selection (SCT-013-000, 2000:1)

For 1.0V output at full-scale current:

| Target Range | R_burden | V @ max | Use Case |
|---|---|---|---|
| 100A | 20Ω | 1.0V | Large commercial |
| 50A | 40Ω | 1.0V | Large compressor |
| 30A | 66Ω | 1.0V | Compressor (3-5 ton) |
| 15A | 133Ω | 1.0V | Small compressor |
| 5A | 400Ω | 1.0V | Fan motor |
| 1A | 2kΩ | 1.0V | Crankcase heater |

Formula: R_burden = V_target / (I_primary / turns_ratio) = V_target × 2000 / I_max

**Note:** R_burden must be 1% tolerance or better for accurate readings. Power
dissipation is negligible (< 1mW for all values above). Use standard 1/4W
through-hole axial resistor bent to 2.54mm pin spacing and inserted into the
burden header socket. No soldering required for burden changes.

### Default Configuration

| Channel | Default CT | R_burden | Notes |
|---|---|---|---|
| Ch1 (Compressor) | SCT-013-030 (voltage) | unpopulated | Or SCT-013-000 + 66Ω |
| Ch2 (Fan) | SCT-013-005 (voltage) | unpopulated | Or SCT-013-000 + 400Ω |
| Ch4 (Crankcase) | SCT-013-005 (voltage) | unpopulated | Or SCT-013-000 + 2kΩ |

**DC blocking caps:** 10μF on both sides (tip and ring) for symmetric DC
blocking. At 60Hz with 10kΩ bias resistors, the high-pass cutoff is 1.6Hz —
transparent to the 60Hz signal. Going smaller than 4.7μF risks attenuation
(0.1μF + 10kΩ = 159Hz cutoff, would attenuate 60Hz).

**TVS input protection:** PESD3V3L2BT,215 (Nexperia, LCSC C55440) — dual
bidirectional TVS in SOT-23 package. One device per CT channel, clamps both
AINxP and AINxN to ±3.3V. The 10kΩ series resistance limits fault current
to < 1mA at clamp. Protects against motor inrush transients, hot-plugging
CT jacks under load, and ESD from handling TRS connectors.

**Vbias generation (1.65V from 3.3V rail):**
```
3.3V ── 1kΩ ──┬── 1kΩ ── GND
              │
             100nF + 10μF
              │
            1.65V out
```

- 1.65V mid-rail bias from 3.3V supply via equal resistor divider
- CT signal swings symmetrically around 1.65V
- Within ADS131M04 ±1.2V input range at PGA=1x (1.65V ± 1.0V peak)

## Simplified 24VAC Inputs (LPS, DFT, Y, O)

With the half-wave power supply design (COM = GND), the 24VAC input signals
are already ground-referenced. The AT3H7C optocouplers and SN74HC14DR Schmitt
triggers from the v2.0 board are no longer needed — replaced by a passive
resistor divider, series diode, unidirectional TVS clamp, and filter cap.

**Parts eliminated per input**: AT3H7C optocoupler, 3× 1.8kΩ resistors,
180Ω resistor, SMF5.0A TVS, 10μF filter cap, SN74HC14DR channel.

**Parts eliminated board-wide**: SN74HC14DR (U27) IC entirely (6 channels,
4 used for inputs, 2 spare).

### Per-Input Circuit

```
24VAC input ── 33kΩ ── 10μF ── 1N4148 ──┬── GPIO (ESP32)
                    (DC block)  (anode→) │
                                   PESD3V3L1BA (unidirectional, cathode to junction)
                                         │
                                       100nF
                                         │
                                    COM/GND
```

- **33kΩ**: Current limiting. At 34V peak: (34V - 0.7V - 3.3V) / 33kΩ =
  0.9mA — safe for both TVS and GPIO
- **10μF**: DC blocking cap. All input signals should be AC — blocks any DC
  offset from triac leakage, wiring faults, or asymmetric transformer loading.
  High-pass cutoff with 33kΩ: ~0.5Hz (transparent to 60Hz)
- **1N4148**: Blocks negative half-cycle. Only positive half reaches GPIO
- **PESD3V3L1BA**: Unidirectional TVS, clamps positive to 3.3V. Protects
  ESP32 GPIO from overvoltage transients
- **100nF**: Low-pass filter for noise rejection. With 33kΩ source impedance,
  cutoff ~48Hz — filters HF switching noise while passing the 60Hz envelope.
  Signal appears as ~3.3V DC (with 8.3ms ripple) when 24VAC is present

### Signal Levels

| Condition | GPIO Voltage | ESP32 Reads |
|---|---|---|
| 24VAC present | ~3.3V (clamped) | HIGH |
| 24VAC absent | 0V (pulled low by 100nF + internal pulldown) | LOW |
| Negative half-cycle | 0V (1N4148 blocks) | LOW |
| Transient spike | 3.3V (TVS clamps) | HIGH (protected) |

### Input Pin Configuration

No change to software — `InputPin` class still reads GPIO with `INPUT_PULLDOWN`
and debounce/validation delay. The 100nF + 33kΩ time constant (3.3ms) is fast
enough for the 500ms polling interval.

| Input | GPIO | Function |
|---|---|---|
| LPS | 15 | Low pressure switch (active LOW = fault) |
| DFT | 16 | Defrost thermostat |
| Y | 17 | Compressor call |
| O | 18 | Reversing valve / cool mode |

### BOM (input section, ×4 channels)

| Ref | Part | Package | Qty | Notes |
|-----|---|---|-----|---|
| R_in1–4 | 33kΩ | 0402 | 4 | Current limiting (1 per input) |
| C_indc1–4 | 10μF | 0805 | 4 | DC blocking (1 per input) |
| D_in1–4 | 1N4148 | SOD-323 | 4 | Negative half-cycle blocking |
| D_tvsin1–4 | PESD3V3L1BA | SOD-323 | 4 | Unidirectional 3.3V TVS clamp |
| C_in1–4 | 100nF | 0402 | 4 | Input filter cap |

**Total: 20 components** replacing 28+ components (4× optocouplers, 16×
resistors, 4× caps, 4× TVS, 1× SN74HC14DR).

## Analog Power Supply (AVDD)

The ADS131M04 analog supply can operate at either 3.3V or 5V (rated 2.4–5.5V).
**Recommended: 3.3V** from the existing digital LDO (U22 TLV76133DCYR).

**Why 3.3V:**
- Input signal range ±1.2V is supply-independent (internal reference spec)
- Voltage reference (24VAC → 0.71V RMS, 1.0V peak) fits ±1.2V ✓
- CT clamp signals (1.65V ± 1.0V) fit ±1.2V ✓
- Single clean supply (LDO is cleaner than ferrite bead filtering)
- Lower power draw (~20mA vs 30mA @ 5V)
- Simpler schematic (no separate 5V rail needed)

```
3.3V LDO ──┬── AVDD (ADS131M04)
(U22)      │
           ├── 10μF (bulk bypass)
           ├── 100nF (high-frequency bypass)
           │
          GND
```

**Component placement:**
- 100nF bypass cap within 5mm of AVDD pin (high-frequency decoupling)
- 10μF bulk cap nearby (transient response)
- Single ground tie point under the ADC (star ground)

**Signal voltage specifications (unchanged):**
- Voltage reference Ch3: 0.71V RMS (1.0V peak) — within ±1.2V ✓
- CT clamp Ch1/2/4: biased 1.65V ± 1.0V swing — within ±1.2V ✓
- Input PGA = 1x, differential mode (±1.2V full-scale input range)

## 3.3V Supply (U22 TLV76133DCYR) — Serves Both Digital and Analog

The single 3.3V LDO output feeds both the ESP32 digital supply (DVDD) and the
ADS131M04 analog supply (AVDD). This creates a single, clean 3.3V domain
across the entire system.

**Two recommended changes to the 3.3V LDO section:**

**1. Increase C12 from 100nF to at least 1μF (recommend 10μF)**

The TLV76133 datasheet specifies 1μF minimum output capacitance for
regulator stability. At 100nF the LDO can oscillate under load transients.
With the ESP32-S3 drawing 300–500mA spikes during WiFi TX, a 10μF output
cap provides better transient response and keeps the regulator stable.

**2. Add bulk capacitance (22–47μF) on 3.3V near the ESP32**

WiFi TX bursts cause sharp current spikes that sag the 3.3V rail. Without
bulk capacitance close to the ESP32 power pins, the voltage can dip below
the brownout detector threshold (~3.0V) causing spurious resets. A 22μF or
47μF ceramic cap placed as close as possible to the ESP32 VDD pins absorbs
these transients.

```
Current:   5V → U22 → C12 (100nF) → 3.3V

Suggested: 5V → U22 → C12 (10μF) → 3.3V ──┬── DVDD (ESP32)
                                           │
                                           ├── C_bulk (22-47μF near ESP32)
                                           │
                                           └── AVDD (ADS131M04)
```

**Benefit of unified 3.3V:**
- Single clean supply simplifies noise management
- No need for separate analog/digital supply rails
- Reduces component count and PCB routing complexity
- LDO PSRR provides excellent ripple rejection for both digital and analog

Schematic: `docs/schematics/SCH_Schematic1_2-Power_2026-03-22.pdf`

## PCB Layout Considerations

### Ground Plane Separation (Critical for 24-bit ADC SNR)

**Why separate grounds:**
- ESP32-S3 WiFi/SPI switching injects noise into shared ground plane
- ADS131M04 (24-bit) is extremely sensitive to ground noise
- Unshielded digital return currents couple into analog signal paths
- Result: degraded SNR, noisy CT clamp readings, poor power factor accuracy

**Recommended stackup (4-layer minimum):**
```
Layer 1: Signal + Power (top)
Layer 2: AGND (analog ground plane, isolated region)
Layer 3: DGND (digital ground plane, full coverage)
Layer 4: Signal (bottom)
```

**Ground plane layout:**

```
┌─────────────────────────────────────────┐
│  CT Clamps │ Voltage Ref │ AGND Island  │
│             (left/analog region)         │
├──────────────────────────────────────────┤
│                                          │
│         ADS131M04 (★ star point)        │
│                                          │
│              ★ AGND ↔ DGND              │  ← Single via
│                                          │     (0Ω jumper
├──────────────────────────────────────────┤     or direct)
│  ESP32-S3 │ SPI Bus │ DGND (full)       │
│        (right/digital region)            │
└──────────────────────────────────────────┘
```

**Ground plane implementation:**

1. **AGND Island (Layer 2):**
   - Isolated copper region under ADS131M04 and CT circuits
   - Includes: ADC, CT jacks, voltage reference circuit, Vbias divider
   - Surrounds ADS131M04 with at least 10mm border (no digital traces/vias)
   - **Single via connection** to DGND directly under ADC

2. **DGND Plane (Layer 3):**
   - Full continuous copper plane
   - Provides return path for all digital circuits (ESP32, SPI, buck converter)
   - High copper density = low impedance for return currents

3. **Star Ground Connection:**
   - **Location:** Directly under ADS131M04 center
   - **Method:** Single via (not a trace bridge) or 0Ω jumper resistor
   - **Size:** At least one 12mil via (or two 10mil vias in parallel)
   - **Purpose:** Merges AGND island and DGND at the point of highest analog sensitivity
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

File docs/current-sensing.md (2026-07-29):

# CT Clamp Current Sensing — Schematic & Parts

## Overview

Two SCT-013-030 split-core CT clamps measure AC current on the compressor and fan
circuits. A custom PCB with an ADS1115 16-bit I2C ADC reads the CT output voltages
in differential mode and reports RMS current to the ESP32. I2C level shifting is
handled by the existing PCA9306DCUR on the main board (3.3V ↔ 5V).

**EasyEDA project**: `SCH_Schematic1_2026-02-28` (Board1, V1.0)

## Important: SCT-013-030 vs SCT-013-000

| Model | Output | Burden Resistor | Max Input |
|---|---|---|---|
| **SCT-013-030** | 0–1V AC (voltage) | Built-in (~62 ohm) | 30A |
| SCT-013-000 | 0–50mA AC (current) | **External required** | 100A |

The **SCT-013-030 has a built-in burden resistor** — it outputs voltage directly.
No external burden resistor is needed.

## Circuit Design
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

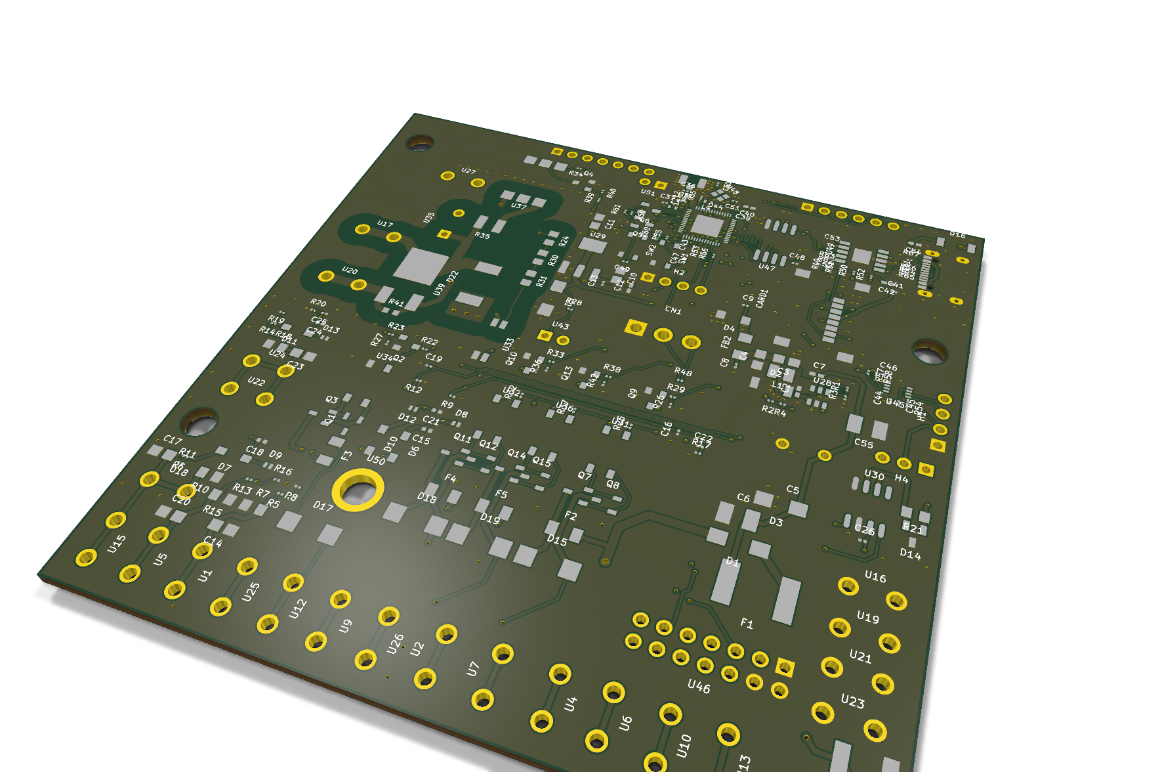
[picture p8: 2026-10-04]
hardware/kicad/out/GoodmanHP-3d.png

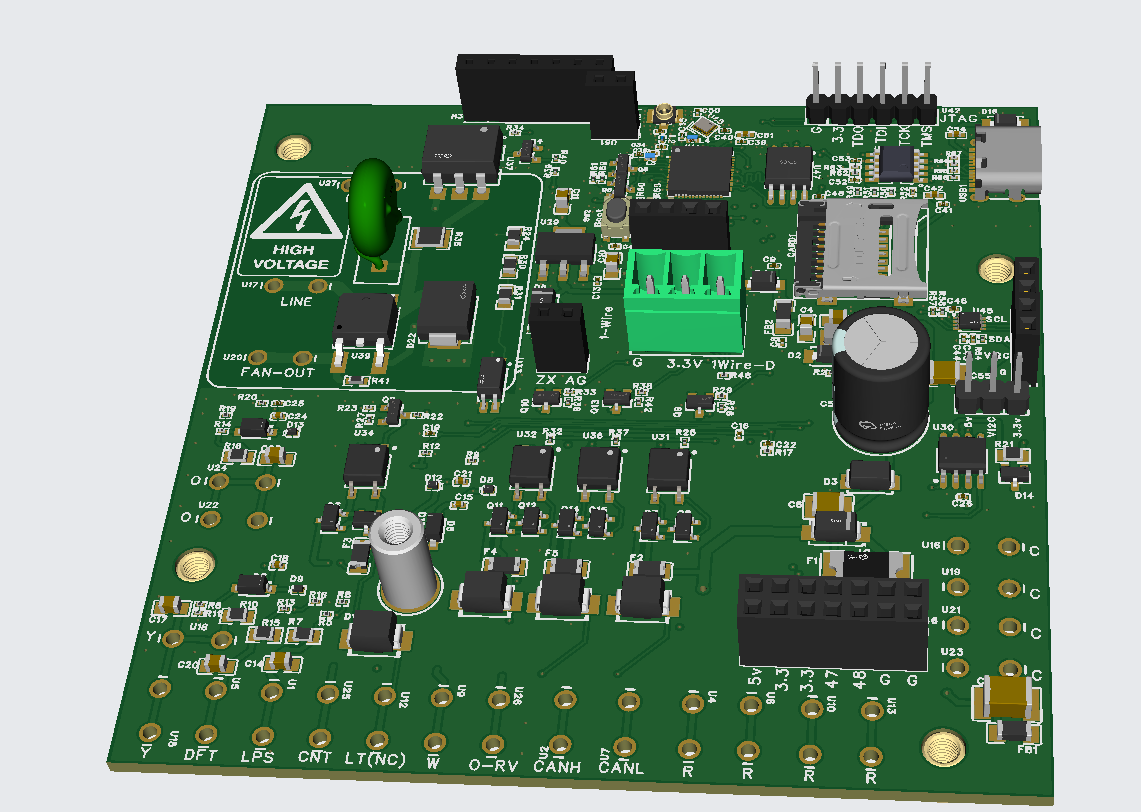
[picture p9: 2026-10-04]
docs/screenshots/board-v8-3d.png

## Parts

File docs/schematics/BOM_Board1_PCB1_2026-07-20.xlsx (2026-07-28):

Quantity | Comment | Designator | Footprint | Value | Manufacturer Part | Manufacturer | Supplier Part | Supplier | No.
1 | 22uF | C1 | C1812 | 22uF | FS43X226K500ERG | PSA(信昌电陶) | C22388553 | LCSC | 1
2 | 100nF | C2,C7 | C0402 | 100nF | GRM155R71H104KE14D | muRata(村田) | C77020 | LCSC | 2
4 | 22uF | C3,C4,C10,C11 | C0805 | 22uF | GRM21BZ71A226ME15L | muRata(村田) | C907991 | LCSC | 3
1 | 1000uF | C5 | CAP-TH_BD16.0-P7.50-D0.8-FD_1 | 1000uF | ERG63V1000M16X26 | JIERR(捷而瑞) | C51904476 | LCSC | 4
1 | 10uF | C6 | C1210 | 10uF | GRM32ER71J106KA12L | muRata(村田) | C437568 | LCSC | 5
6 | 1uF | C8,C9,C37,C44,C47,C49 | C0201 | 1uF | GRM033R60J105KEA2D | muRata(村田) | C76929 | LCSC | 6
4 | 10uF | C12,C40,C42,C54 | C0402 | 10uF | CL05A106MQ5NUNC | SAMSUNG(三星) | C15525 | LCSC | 7
16 | 100nF | C13,C16,C19,C22,C25,C26,C35,C38,C39,C41,C43,C45,C46,C48,C52,C53 | C0201 | 100nF | GRM033C71C104KE14D | muRata(村田) | C85923 | LCSC | 8
7 | 2.2uF | C14,C17,C20,C23,C28,C30,C33 | C0805 | 2.2uF | HHV0805R7225K101NSLJ | Chinocera(华瓷) | C22367838 | LCSC | 9
4 | 4.7uF | C15,C18,C21,C24 | C0402 | 4.7uF | 0402X475K160NT | FH(风华) | C20624278 | LCSC | 10
3 | 100nF | C27,C29,C32 | C0805 | 100nF | CL21B104KCFNNNE | SAMSUNG(三星) | C28233 | LCSC | 11
1 | 220nF | C31 | C2220 | 220nF | FV55X224K102EHG | PSA(信昌电陶) | C1021535 | LCSC | 12
2 | 1.2pF | C34,C36 | C0201 | 1.2pF | GRM0335C1H1R2BA01D | muRata(村田) | C85895 | LCSC | 13
2 | 27pF | C50,C51 | C0201 | 27pF | GRM0335C1H270GA01D | muRata | C384976 | LCSC | 14
1 | 472192001 | CARD1 | TF-SMD_472192001 |  | 472192001 | MOLEX | C164170 | LCSC | 15
1 | DB2EVC-3.81-3P-GN | CN1 | CONN-TH_3P-P3.81_DB2EVC-3.81-3P |  | DB2EVC-3.81-3P-GN | DORABO(地博电气) | C395692 | LCSC | 16
1 | SM4007PL | D1 | SOD-123F_L2.8-W1.8-LS3.7-RD |  | SM4007PL | MDD(辰达半导体) | C64898 | LCSC | 17
2 | PMEG6020EP,115 | D2,D16 | SOD-128_L3.7-W2.5-LS4.7-FD |  | PMEG6020EP,115 | Nexperia(安世) | C179433 | LCSC | 18
1 | SMAJ36CA | D3 | SMA_L4.2-W2.7-LS5.0-BI |  | SMAJ36CA | GOODWORK(固得沃克) | C908830 | LCSC | 19
1 | SMF5.0A | D4 | SOD-123FL_L2.8-W1.9-LS3.7-RD |  | SMF5.0A | JSMSEMI(杰盛微) | C2857263 | LCSC | 20
1 | SMAJ3.3A | D5 | SMA_L4.3-W2.7-LS5.1-RD |  | SMAJ3.3A | DOWO(东沃) | C22365220 | LCSC | 21
4 | 1N4148W-7-F | D6,D7,D10,D11 | SOD-123_L2.7-W1.6-LS3.7-RD-1 |  | 1N4148W-7-F | DIODES(美台) | C83528 | LCSC | 22
4 | BZX884-B3V3,315 | D8,D9,D12,D13 | SOD-882_L1.0-W0.6-RD |  | BZX884-B3V3,315 | Nexperia(安世) | C551199 | LCSC | 23
1 | ESDCAN24-2BLY | D14 | SOT-23-3_L2.9-W1.3-P1.90-LS2.4-BL-2 |  | ESDCAN24-2BLY | TECH PUBLIC | C2937021 | LCSC | 24
1 | SMAJ45CA | D15 | SMA_L4.3-W2.7-LS5.1-BI |  | SMAJ45CA | TECH PUBLIC(台舟) | C53278443 | LCSC | 25
1 | 2920L050/90GR | F1 | F2920 |  | 2920L050/90GR | LUTE(陆特) | C41414044 | LCSC | 26
2 | BLM31PG601SN1L | FB1,FB2 | L1206 |  | BLM31PG601SN1L | muRata(村田) | C16902 | LCSC | 27
2 | 2.54-1*4P母 | H1,H2 | HDR-TH_4P-P2.54-V-F |  | 2.54-1*4P母 | BOOMELE(博穆精密) | C2718488 | LCSC | 28
1 | PM254V-11-07-H85 | H3 | HDR-TH_7P-P2.54-V-F |  | PM254V-11-07-H85 | XFCN(兴飞) | C2832270 | LCSC | 29
1 | PZ254V-11-03P | H4 | HDR-TH_3P-P2.54-V-M_PZ254V-11-03P |  | PZ254V-11-03P | XFCN(兴飞) | C2937625 | LCSC | 30
1 | 10uH | L1 | IND-SMD_L2.5-W2.0 | 10uH | FTC252012S100MBCA | cjiang(长江微电) | C5832376 | LCSC | 31
1 | 2.7nH | L2 | L0201 | 2.7nH | LQP03HQ2N7B02D | muRata(村田) | C7216765 | LCSC | 32
2 | 20nH | L3,L4 | IND-SMD_L1.2-W0.6-1 | 20nH | SCW1005C20NJST | Sunltech(顺磁) | C330860 | LCSC | 33
2 | HSS2N12A | Q1,Q3 | SOT-23-3_L3.0-W1.7-P0.95-LS2.9-BR |  | HSS2N12A | HUASHUO(华朔) | C53243986 | LCSC | 34
2 | L2N7002SLLT1G | Q2,Q4 | SOT-23-3_L3.0-W1.7-P0.95-LS2.9-BR |  | L2N7002SLLT1G | LRC(乐山无线电) | C22446827 | LCSC | 35
2 | SS8050 | Q5,Q6 | SOT-23-3_L2.9-W1.3-P1.90-LS2.4-BR |  | SS8050 | JSMSEMI(杰盛微) | C916392 | LCSC | 36
6 | 33kΩ | R1,R5,R6,R13,R14,R28 | R0201 | 33kΩ | 0201WMF3302TEE | UNI-ROYAL(厚声) | C473534 | LCSC | 37
1 | 9.31kΩ | R2 | R0201 | 9.31kΩ | 0201WMF9311TEE | UNI-ROYAL(厚声) | C423401 | LCSC | 38
1 | 2kΩ | R3 | R0201 | 2kΩ | 0201WMF2001TEE | UNI-ROYAL(厚声) | C270358 | LCSC | 39
1 | 1.8kΩ | R4 | R0201 | 1.8kΩ | 0201WMF1801TEE | UNI-ROYAL(厚声) | C473568 | LCSC | 40
7 | 5.6kΩ | R7,R10,R15,R18,R30,R42,R47 | R0805 | 5.6kΩ | ERJP06F5601V | PANASONIC(松下) | C441985 | LCSC | 41
17 | 10kΩ | R8,R11,R16,R19,R27,R29,R38,R40,R46,R49,R50,R51,R52,R55,R59,R60,R61 | R0201 | 10kΩ | 0201WMF1002TEE | UNI-ROYAL(厚声) | C473048 | LCSC | 42
4 | 1MΩ | R9,R12,R17,R20 | R0201 | 1MΩ | RC0201FR-071ML | YAGEO(国巨) | C295786 | LCSC | 43
1 | 120Ω | R21 | R0805 | 120Ω | CRCW0805120RFKEAHP | VISHAY(威世) | C844392 | LCSC | 44
10 | 180Ω | R22,R23,R24,R25,R32,R33,R34,R39,R43,R44 | R0201 | 180Ω | NQ01WMJ0181TEE | UNI-ROYAL(厚声) | C965335 | LCSC | 45
3 | 47Ω | R26,R36,R45 | R0805 | 47Ω | 0805W8F470JT5E | UNI-ROYAL(厚声) | C17714 | LCSC | 46
1 | 300kΩ | R31 | R0603 | 300kΩ | FRC0603F3003TS | FOJAN(富捷) | C2930091 | LCSC | 47
1 | 390Ω | R35 | R1210 | 390Ω | FRC1210J391 TS | FOJAN(富捷) | C2960731 | LCSC | 48
1 | 39Ω | R37 | R2512 | 39Ω | RC2512FK-7W39RL | YAGEO | C7337035 | LCSC | 49
1 | 10kΩ | R41 | R0603 | 10kΩ | 0603WAF1002T5E | UNI-ROYAL(厚声) | C25804 | LCSC | 50
5 | 4.7kΩ | R48,R57,R58,R66,R67 | R0201 | 4.7kΩ | 0201WMF4701TEE | UNI-ROYAL(厚声) | C270346 | LCSC | 51
6 | 33Ω | R53,R56,R62,R63,R64,R65 | R0201 | 33Ω | 0201WMJ0330TEE | UNI-ROYAL(厚声) | C423356 | LCSC | 52
1 | 200kΩ | R54 | R0201 | 200kΩ | 0201WMF2003TEE | UNI-ROYAL(厚声) | C270357 | LCSC | 53
1 | 2337019-1 | RF1 | ANT-SMD_2337019-1 |  | 2337019-1 | TE Connectivity(泰科电子) | C434807 | LCSC | 54
2 | RKB2SJG250SMTRLFS | SW1,SW2 | SW-SMD_4P-L4.2-W3.2-P2.15-LS4.6 |  | RKB2SJG250SMTRLFS | C&K | C2927788 | LCSC | 55
23 | 1217861-1 Faston | U1,U2,U4,U5,U6,U7,U9,U10,U12,U13,U15,U16,U17,U18,U19,U20,U21,U22,U23,U24,U25,U26,U27 | 1217861-1 |  |  |  | C428480 | LCSC | 56
4 | SMTSO3280CTJ | U3,U8,U11,U14 | SMD_BD5.6-L5.6-W5.6-D4.1 |  | SMTSO3280CTJ | Sinhoo(雄和远景) | C2928174 | LCSC | 57
1 | LGS5145 | U28 | SOT-23-6_L2.9-W1.7-P0.95-LS2.8-BL |  | LGS5145 | Legend-Si(棱晶半导体) | C5123971 | LCSC | 58
1 | TLV76133DCYR | U29 | SOT-223-4_L6.5-W3.5-P2.30-LS7.0-TR |  | TLV76133DCYR | TI(德州仪器) | C7527500 | LCSC | 59
1 | SN65HVD230DR-JSM | U30 | SOP-8_L4.9-W3.9-P1.27-LS6.0-BL |  | SN65HVD230DR-JSM | JSMSEMI(杰盛微) | C46596299 | LCSC | 60
3 | KMOC3021S TL | U31,U36,U40 | SMD-6_5P-L7.3-W6.5-P2.54-LS10.0-BL-PE5 |  | KMOC3021S TL | cosmo(冠西) | C920681 | LCSC | 61
4 | BT138S-800E | U32,U38,U39,U41 | TO-252-2_L6.6-W6.1-P4.57-LS10.1-BR-CW |  | BT138S-800E | FUXINSEMI(富芯森美) | C5380690 | LCSC | 62
1 | AT3H4B-CuH-S | U33 | SSOP-4_L2.7-W4.6-P1.27-LS7.0-TL |  | AT3H4B-CuH-S | AOTE(奥特) | C20612635 | LCSC | 63
1 | GAQV1122S | U34 | SOP-4_L4.3-W4.4-P2.54-LS6.8-TR |  | GAQV1122S | SUPSiC(国晶微半导体) | C22385006 | LCSC | 64
1 | B59850C0130A070 | U35 | RES-TH_L11.0-W5.0-P5.00-D0.8 |  | B59850C0130A070 | TDK | C125471 | LCSC | 65
1 | MOC3041SM | U37 | SMD-6_L8.8-W6.4-P2.54-LS9.4-BL |  | MOC3041SM | AOTE(奥特) | C22373366 | LCSC | 66
1 | 2541WV-06P | U42 | HDR-TH_6P-P2.54-V-M |  | 2541WV-06P | HanElectricity(瀚源) | C5383115 | LCSC | 67
1 | ZX-PM2.54-1-2PY | U43 | HDR-TH_2P-P2.54-V-F |  | ZX-PM2.54-1-2PY | Megastar(兆星) | C7499322 | LCSC | 68
1 | ESP32-S3R8 | U44 | QFN-56_L7.0-W7.0-P0.40-TL-EP4.0 |  | ESP32-S3R8 | ESPRESSIF(乐鑫) | C2913194 | LCSC | 69
1 | PCA9306DCUR | U45 | SSOP-8_L2.0-W2.3-P0.50-LS3.1-BR |  | PCA9306DCUR | TI(德州仪器) | C33196 | LCSC | 70
1 | 2541FV-2x7P-B | U46 | HDR-TH_2541FV-2X7P-B |  | 2541FV-2x7P-B | HanElectricity(瀚源) | C25503125 | LCSC | 71
1 | W25Q128JVSIQ | U47 | SOIC-8_L5.3-W5.3-P1.27-LS8.0-BL |  | W25Q128JVSIQ | Winbond(华邦) | C113767 | LCSC | 72
1 | 40MHz | U48 | CRYSTAL-SMD_4P-L2.0-W1.6-BL | 40MHz | XTM32040000PT00351001 | TOGNJING | C42464327 | LCSC | 73
1 | CH340K | U49 | ESOP-10_L4.9-W3.9-P1.00-LS6.2-BL-EP |  | CH340K | WCH(南京沁恒) | C968586 | LCSC | 74
1 | TYPE-C 16PIN 2MD(073) | USB1 | USB-C-SMD_TYPE-C-6PIN-2MD-073 |  | TYPE-C 16PIN 2MD(073) | SHOU HAN(首韩) | C2765186 | LCSC | 75

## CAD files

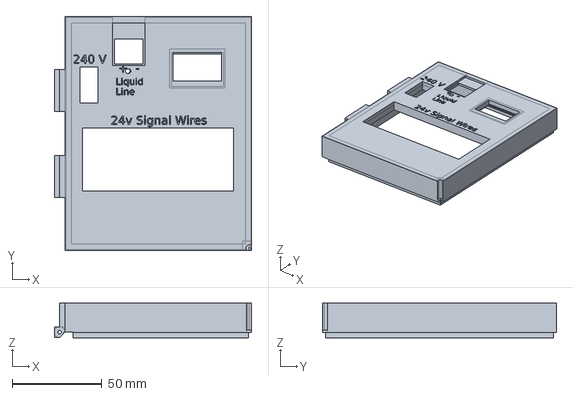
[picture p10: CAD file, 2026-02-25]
shell/3DShell_GoodmanHPv3_T_3.5mm_TC_hinged.step
110.2 x 130.6 x 19.5 mm

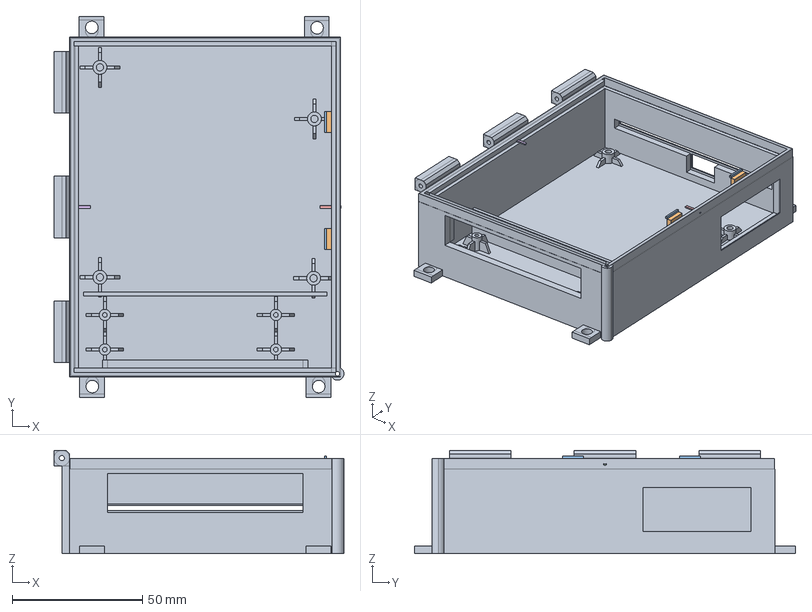
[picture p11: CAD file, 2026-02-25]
shell/3DShell_GoodmanHPv3_B_3.5mm_hinged.step
111.4 x 146.5 x 39.7 mm

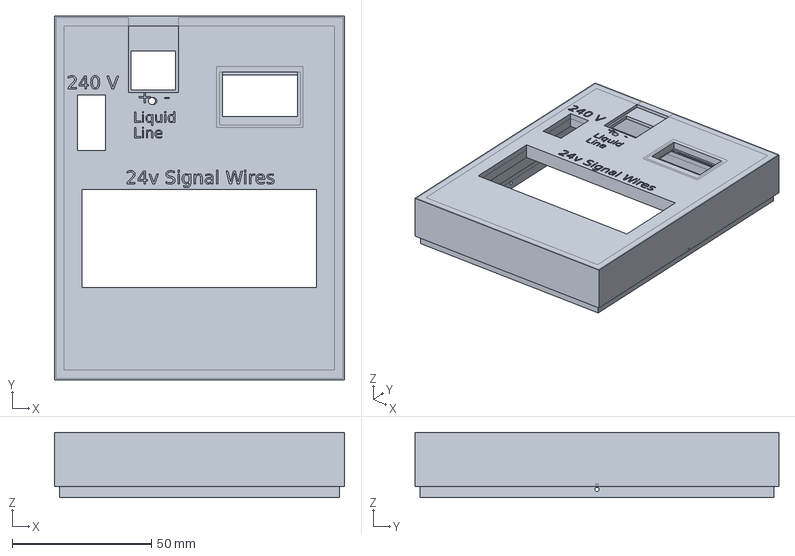
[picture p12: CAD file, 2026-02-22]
shell/3DShell_GoodmanHPv3_T_3.5mm_TC_flipped.step
104.2 x 130.6 x 23.5 mm

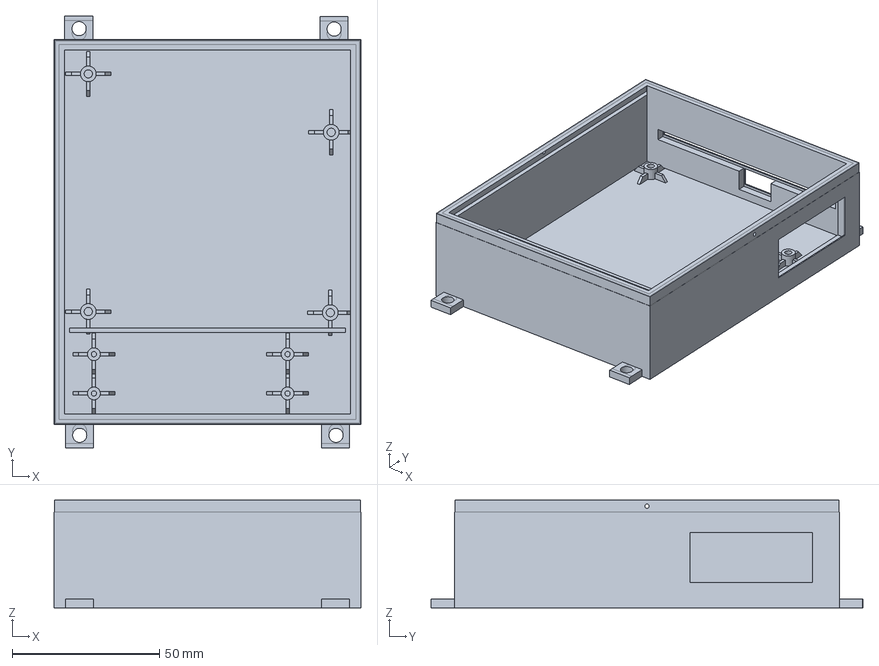
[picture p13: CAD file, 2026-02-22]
shell/3DShell_GoodmanHPv3_B_3.5mm_flipped.step
104.2 x 146.5 x 36.5 mm

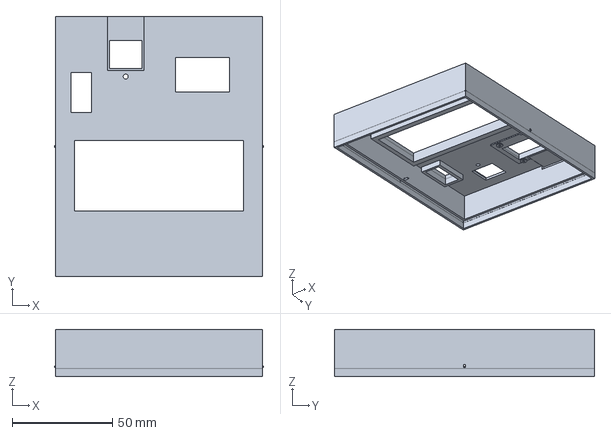
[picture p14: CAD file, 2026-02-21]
shell/3DShell_GoodmanHPv3_T_3mm_TC.step
104.2 x 129.6 x 23.5 mm

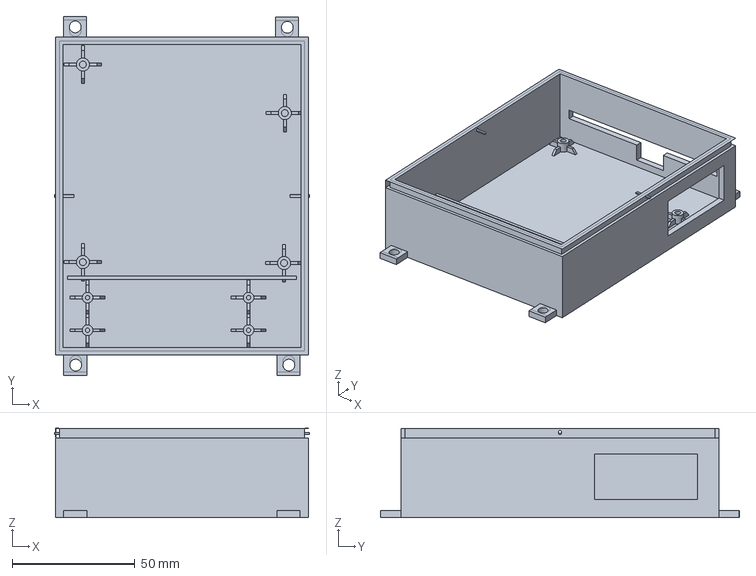
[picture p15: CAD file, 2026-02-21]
shell/3DShell_GoodmanHPv3_B_3mm.step
104.2 x 146.5 x 36.5 mm

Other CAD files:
shell/3DShell_GoodmanHPv3_B_3.5mm_flipped.stl
shell/3DShell_GoodmanHPv3_B_3.5mm_hinged.stl
shell/3DShell_GoodmanHPv3_B_3mm.stl
shell/3DShell_GoodmanHPv3_T_3.5mm_TC_flipped.stl
shell/3DShell_GoodmanHPv3_T_3.5mm_TC_hinged.stl
shell/3DShell_GoodmanHPv3_T_3mm_TC.stl

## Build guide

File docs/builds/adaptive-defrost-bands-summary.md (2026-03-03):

# Adaptive Defrost Bands Based on Ambient Temperature

**Date:** 2026-03-03

## Overview

Replaced the single defrost runtime threshold (default 90 min) with 3 ambient temperature bands — each with its own runtime threshold, minimum defrost time, and condenser exit temp. Colder ambient temps cause faster ice buildup, so the Cold band triggers defrost sooner with a lower exit temp.

## Band Defaults

| Band | Ambient Range | Runtime Threshold | Min Defrost | Exit Temp |
|---|---|---|---|---|
| **Cold** | ≤ 23°F | 30 min | 2 min | 50°F |
| **Mid** | 23–31°F | 60 min | 1.5 min | 55°F |
| **Warm** | ≥ 31°F | 90 min | 1 min | 60°F |

All values configurable via config page. Two breakpoint temperatures (`coldMaxTemp`, `warmMinTemp`) define the band boundaries.

## Files Modified (11 files)

| File | Changes |
|---|---|
| `include/Config.h` | Replaced 3 single defrost fields with 11 band fields (2 breakpoints + 3x3 band params) in `ProjectInfo` |
| `include/GoodmanHP.h` | Added `DefrostBandName` enum, `DefrostBand` struct, replaced old member vars/getters/setters with band-aware versions, added `selectDefrostBand()` |
| `src/GoodmanHP.cpp` | Constructor inits band array, `selectDefrostBand()` reads ambient temp and returns band, `checkDefrostNeeded()` uses band-specific thresholds, `startSoftwareDefrost()` snapshots band, exit criteria use snapshot, `restoreSoftwareDefrost()` snapshots on boot, `forceDefrost()` selects band |
| `src/Config.cpp` | `loadTempConfig()`: migration from old single-value fields to bands, load band sub-objects. `saveConfiguration()` + `updateConfig()`: write band structure, remove old keys |
| `src/main.cpp` | ProjectInfo literal: 3 values → 11 band values. Boot: 3 `set*` calls → `setColdMaxTempF`, `setWarmMinTempF`, 3x `setDefrostBand` |
| `src/WebHandler.cpp` | Config GET: 13 band fields. Config POST: parse/validate with lambda. `/state`: `defrostBand` + `defrostBandThresholdMin` |
| `src/HttpsServer.cpp` | Mirrored all WebHandler changes for config GET/POST and `/state` |
| `src/MQTTHandler.cpp` | Added `defrostBand` and `defrostBandThresholdMin` to MQTT state payload |
| `src/DisplayManager.cpp` | Heat runtime line: `HRT: 42/60m (Mid)` format |
| `data/www/config.html` | Replaced Defrost Controls with band table (breakpoints + 3-row table), `updateBandRanges()` for live range labels |
| `data/www/dashboard.html` | Heat runtime: `Heat RT: 42m / 60m (Mid)` format |
| `data/www/pins.html` | Heat runtime flag: includes band threshold and name |

## Key Design Decisions

- **Band snapshot on defrost start**: Parameters are frozen when defrost begins, preventing mid-cycle parameter jumps if ambient drifts
- **Backward compatibility**: Old single-value configs auto-migrate (Warm = old values, Mid/Cold derived proportionally)
- **No ambient data = Warm band**: Most conservative (longest runtime threshold before defrost)
- **Validation rules**: Breakpoints enforce gap (`coldMax < warmMin`), runtime 1–120 min, min defrost 30–600 sec, exit temp 30–120°F

## Config JSON Structure

```json
"defrost": {
    "active": false,
    "coldMaxTemp": 23.0,
    "warmMinTemp": 31.0,
    "cold": { "runtimeThresholdMs": 1800000, "minRuntimeMs": 120000, "exitTempF": 50.0 },
    "mid":  { "runtimeThresholdMs": 3600000, "minRuntimeMs": 90000, "exitTempF": 55.0 },
    "warm": { "runtimeThresholdMs": 5400000, "minRuntimeMs": 60000, "exitTempF": 60.0 }
}
```

## API Changes

### `/state` JSON (new fields)
- `defrostBand` — active band name: `"Cold"`, `"Mid"`, or `"Warm"`
- `defrostBandThresholdMin` — active band's runtime threshold in minutes

### Config GET/POST (replaced fields)
Removed: `defrostMinRuntimeSec`, `defrostExitTempF`, `heatRuntimeThresholdMin`

Added:
- `defrostColdMaxTemp`, `defrostWarmMinTemp` — breakpoint temperatures
- `defrostColdRuntimeMin`, `defrostColdMinRuntimeSec`, `defrostColdExitTempF` — Cold band
- `defrostMidRuntimeMin`, `defrostMidMinRuntimeSec`, `defrostMidExitTempF` — Mid band
- `defrostWarmRuntimeMin`, `defrostWarmMinRuntimeSec`, `defrostWarmExitTempF` — Warm band

## Migration

On config load, if old single-value fields exist (`heatRuntimeThresholdMs`, `minRuntimeMs`, `exitTempF`) and new `cold` sub-object doesn't exist:
- **Warm band** = old runtime, min defrost ×⅓, old exit temp
- **Mid band** = runtime ×⅔, min defrost ×½, exit temp −5°F
- **Cold band** = runtime ×⅓, min defrost ×⅔, exit temp −10°F

Old keys are removed on next `updateConfig()` save.

## Verification Steps

1. `pio run -e freenove_esp32_s3_wroom` — clean build, no warnings
2. OTA upload to device, upload config.html via LittleFS
3. Config page: verify band table loads with correct defaults, breakpoint changes update range labels
4. Save config → verify JSON on SD card has new band structure
5. Dashboard: verify `Heat RT: Xm / Ym (Band)` format with correct active band
6. Test band switching: use failover test to simulate different ambient temps, verify band changes
7. Migration: device with old single-value config should auto-migrate to bands on first load

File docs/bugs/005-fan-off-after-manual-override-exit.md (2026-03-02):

# BUG-005: FAN not restored after manual override exit

**Date**: 2026-03-01
**Severity**: Low
**Status**: Fixed
**Affected versions**: v1.1 through v1.2-rc7
**Fixed in**: v1.2-rc8

## Symptom

State validator logged:
```
[ERROR] [HP] STATE CHECK: FAN off in HEAT — forcing ON
```

After disabling manual override, FAN remained OFF while in HEAT mode with
CNT active. The state validator caught and corrected it.

## Impact

- FAN was off for up to 10 seconds (one validator cycle) after override exit
- Validator auto-corrected, no equipment damage
- Brief period of compressor running without condenser airflow — minimal risk
  given the short duration

## Root Cause

When manual override exits (`setManualOverride(false)`), all outputs are
turned OFF and `_cntActivated` is reset. However, `_yWasActive` was NOT
reset. Since Y was still active the entire time, the Y activation edge
detection in `checkYAndActivateCNT()` never re-fired:

```cpp
if (yActive && !_yWasActive) {   // _yWasActive still true — edge never fires
    fan->turnOn();                // FAN never restored
}
```

CNT was immediately reactivated (30s already elapsed from original Y
activation), but FAN stayed off because only the Y activation edge turns
FAN on.

## Fix

Reset `_yWasActive = false` when manual override exits. This causes the
Y activation edge to fire naturally in the next `update()` cycle, turning
FAN on and restarting the normal activation sequence.

## Timeline (from logs)

```
04:09:33  MANUAL OVERRIDE enabled
04:09:54  Manual toggle: RV ON, W ON
04:10:06  MANUAL OVERRIDE disabled, all outputs OFF
04:10:06  Y active for 30s, CNT activated           ← CNT restored
04:10:06  STATE CHECK: FAN off in HEAT — forcing ON  ← FAN was NOT restored
04:10:36  State check OK: HEAT [FAN=ON CNT=ON]       ← validator fixed it
```

## Affected Code

- `src/GoodmanHP.cpp`: `setManualOverride()` — added `_yWasActive = false`

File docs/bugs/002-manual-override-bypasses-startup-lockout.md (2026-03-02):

# BUG-002: Manual override bypasses startup lockout — CNT can be activated during sensor stabilization period

**Severity:** High (safety)
**Date discovered:** 2026-02-22
**Affected files:** `src/GoodmanHP.cpp`, `include/GoodmanHP.h`, `src/WebHandler.cpp`, `src/HttpsServer.cpp`
**Fixed in:** `4e357ff` ("Block manual override during startup lockout to prevent CNT activation")

---

## Summary

The manual override feature does not check the startup lockout flag, allowing a user to enable manual override and turn on the compressor contactor (CNT) during the 180-second startup lockout period. This lockout exists to prevent output activation before temperature sensors have stabilized and the state machine has assessed conditions. A secondary issue in the short cycle protection condition makes it ineffective for the first 30+ seconds after boot.

## Impact

- Compressor can be activated before sensors have stabilized, bypassing safety checks (low temp protection, LPS fault, high suction temp, RV fail)
- The 180-second startup lockout — designed to prevent exactly this — is rendered ineffective by manual override
- Short cycle protection at boot is not meaningful: `initPin()` sets `_changeOffTick = millis()`, so the 30-second short cycle timer starts from boot time, not from a real CNT off event

## Incident Timeline (2026-02-22)

All times from device log at `192.168.1.138`.

| Time | Event | Notes |
|---|---|---|
| ~07:16:47 | Boot. Outputs verified OFF. **180s startup lockout begins** | `_changeOffTick = millis()` set by `initPin()` |
| 07:17:01 | NTP synced, MQTT connected | 14s after boot |
| **07:17:56** | **Manual override enabled** | 69s after boot — **during startup lockout** |
| **07:18:02** | **CNT turned ON via manual override** | 75s after boot — **during startup lockout** |
| 07:18:05 | CNT state confirmed ON (3s activation delay) | Compressor physically starts |
| 07:18:06 | CNT turned OFF (user noticed the issue) | |
| **07:19:47** | Startup lockout completes (180s elapsed) | 111s **after** CNT was already activated |

## Root Cause Analysis

### Bug 1: `setManualOverride()` does not check `_startupLockout`

`GoodmanHP::setManualOverride()` (`GoodmanHP.cpp:1442`) accepted `on = true` without verifying that the startup lockout period had completed:

```cpp
void GoodmanHP::setManualOverride(bool on) {
    // No _startupLockout check!
    if (on && !_manualOverride) {
        _manualOverride = true;
        _manualOverrideStart = millis();
        // ...
    }
}
```

The `update()` function (line 157–166) correctly returns early during `_startupLockout`, but `setManualOverride()` is called from the web API handlers — a completely separate code path that bypasses `update()`.

### Bug 2: `setManualOutput()` does not check `_startupLockout`

`GoodmanHP::setManualOutput()` (`GoodmanHP.cpp:1467`) also had no startup lockout check, so even if `setManualOverride()` had been blocked, a stale manual override session from a previous boot could theoretically allow output activation:

```cpp
String GoodmanHP::setManualOutput(const String& name, bool on) {
    if (!_manualOverride) return "Manual override not active";
    // No _startupLockout check!
    OutPin* pin = getOutput(name);
    // ...
}
```

### Bug 3: Short cycle protection condition is overly permissive

The short cycle check in `setManualOutput()` used an AND condition that made it ineffective after 30 seconds:

```cpp
if (offElapsed < 5UL * 60 * 1000 && offElapsed < _cntShortCycleMs) {
```

After boot, `_changeOffTick` is set to `millis()` by `initPin()`. At 75 seconds post-boot:
- `offElapsed = 75000ms`
- `offElapsed < _cntShortCycleMs` = `75000 < 30000` = **false**
- Entire AND condition is **false** — short cycle does not block

The `5UL * 60 * 1000` (5-minute) term is redundant since `_cntShortCycleMs` (30s) is always shorter. The only purpose it served was in `isShortCycleProtectionActive()` where it determines how long the "SC" pill shows on the dashboard — but that's a display concern, not a safety gate.

### Why the normal code path was safe

The `update()` function has a startup lockout guard at the very top (line 157–166):

```cpp
void GoodmanHP::update() {
    if (_startupLockout) {
        if (millis() - _startupTick >= STARTUP_LOCKOUT_MS) {
            _startupLockout = false;
        } else {
            return;  // Skip ALL state machine logic
        }
    }
    if (_manualOverride) {
        return;  // Skip state machine when in manual mode
    }
    // ... rest of state machine
}
```

This correctly blocks the automatic state machine during lockout. But the manual override API (`setManualOverride` + `setManualOutput`) is invoked directly from web request handlers, never passing through `update()`.

## Fix Applied

Four changes across four files:

### 1. `setManualOverride()` returns error during startup lockout (`GoodmanHP.cpp`)

Changed return type from `void` to `String`. Added startup lockout check at the top:

```cpp
String GoodmanHP::setManualOverride(bool on) {
    if (on && _startupLockout) {
        uint32_t remainSec = (getStartupLockoutRemainingMs() + 999) / 1000;
        Log.warn("HP", "Manual override blocked: startup lockout (%us remaining)", remainSec);
        return "Startup lockout: " + String(remainSec) + "s remaining";
    }
    // ... rest of function
    return "";
}
```

### 2. `setManualOutput()` blocks during startup lockout (`GoodmanHP.cpp`)

Defense-in-depth — even if manual override is somehow active during lockout:

```cpp
String GoodmanHP::setManualOutput(const String& name, bool on) {
    if (!_manualOverride) return "Manual override not active";
    if (_startupLockout) return "Startup lockout active";
    // ...
}
```

### 3. Simplified short cycle condition (`GoodmanHP.cpp`)

Removed redundant 5-minute window from the AND condition:

```cpp
// Before:
if (offElapsed < 5UL * 60 * 1000 && offElapsed < _cntShortCycleMs) {

// After:
if (offElapsed < _cntShortCycleMs) {
```

### 4. Web API handlers return error to client (`WebHandler.cpp`, `HttpsServer.cpp`)

Both HTTP and HTTPS `/pins` POST handlers now check the return value and send a 409 response with the error message:

```cpp
String err = _hpController->setManualOverride(on);
if (err.length() > 0) {
    resp["error"] = err;
    // ... send 409 Conflict
    return;
}
```

The `pins.html` frontend already handled `d.error` responses (line 158), reverting the checkbox and displaying an alert — no frontend changes needed.

### 5. Header declaration updated (`GoodmanHP.h`)

```cpp
// Before:
void setManualOverride(bool on);

// After:
String setManualOverride(bool on);
```

## Files Changed

- `include/GoodmanHP.h` — `setManualOverride()` return type `void` -> `String`
- `src/GoodmanHP.cpp` — Startup lockout checks in `setManualOverride()` and `setManualOutput()`, simplified short cycle condition
- `src/WebHandler.cpp` — Error handling for manual override toggle
- `src/HttpsServer.cpp` — Error handling for manual override toggle (HTTPS path)

## How to Reproduce

1. Upload firmware and reboot the device
2. Immediately open the Pins page in the browser (within 180 seconds of boot)
3. Enable "Manual Override" checkbox
4. Toggle CNT output ON
5. **Before fix:** CNT activates during startup lockout — compressor starts before sensors stabilize
6. **After fix:** Checkbox reverts with alert "Startup lockout: Xs remaining"

## Verification (2026-02-22)

Tested on device at `192.168.1.138` immediately after firmware upload and reboot.

| Test | Time into lockout | Result |
|---|:---:|---|
| `POST /pins {"manualOverride":true}` | 14s (166s remaining) | **Blocked** — `{"error":"Startup lockout: 166s remaining"}` / HTTP 409 |
| `POST /pins {"manualOverride":true}` | 25s (155s remaining) | **Blocked** — `{"error":"Startup lockout: 155s remaining"}` / HTTP 409 |
| `POST /pins {"manualOverride":true}` | After lockout expired | **Allowed** — `{"status":"ok","manualOverride":true}` / HTTP 200 |
| `POST /pins {"manualOverride":false}` | — | **OK** — `{"message":"Manual override disabled, all outputs OFF"}` |

## Lessons Learned

- Web API endpoints that control outputs must enforce the same safety invariants as the state machine — they share the same physical outputs but take completely different code paths
- Defense-in-depth: both the entry point (`setManualOverride`) and the action (`setManualOutput`) should independently verify preconditions
- `initPin()` setting `_changeOffTick = millis()` at boot creates a synthetic "off event" that starts the short cycle timer from boot — this is acceptable for the normal state machine (which has its own startup lockout), but exposed a gap when manual override bypassed that lockout
- Compound conditions with AND (`a && b`) where `b` is strictly tighter than `a` make `a` dead code — simplify to just `b`

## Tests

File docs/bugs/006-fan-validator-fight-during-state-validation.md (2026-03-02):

# BUG-006: FAN validator fight during state validation window

**Date**: 2026-03-01
**Severity**: Low
**Status**: Fixed
**Affected versions**: v1.2-rc4 through v1.2-rc7 (state validation feature)
**Fixed in**: v1.2-rc8

## Symptom

Two consecutive STATE CHECK errors within 30 seconds:
```
[ERROR] [HP] STATE CHECK: FAN on in OFF — forcing OFF
[ERROR] [HP] STATE CHECK: FAN off in HEAT — forcing ON
```

The validator forced FAN off (wrong for pending state), then immediately had
to force it back on (right for actual state). Double-correction.

## Impact

- FAN toggled OFF then ON within ~30 seconds
- Validator auto-corrected both times, no equipment damage
- Cosmetic: two ERROR log entries for a transient that would have self-resolved

## Root Cause

**State validation delay** creates a window where the state label doesn't
reflect the actual operating mode.

When LOW_TEMP exits → state=OFF with 30s validation hold. During that window:

1. Y activates → `checkYAndActivateCNT()` turns FAN ON (correct behavior)
2. Validator runs, sees state=OFF → OFF table says FAN=0 → forces FAN OFF
3. Validation completes → state transitions OFF → HEAT
4. Validator runs, sees state=HEAT with CNT=ON → HEAT table says FAN=1 → forces FAN ON

The validator enforced table rules against a state label that was stale
(pending transition). The Y activation logic was correct for the pending
state (HEAT), but the validator only knew about the current label (OFF).

## Fix

Skip output validation during active state validation hold:

```cpp
if (_startupLockout || _manualOverride || _stateValidationActive) return;
```

This is consistent with existing skip logic for startup lockout and manual
override — both are transitional periods where the state label may not match
the actual operating mode. The state machine actively manages outputs during
validation, so table-driven enforcement is unnecessary and counterproductive.

## Timeline (from logs)

```
04:04:08  State check OK: HEAT [FAN=ON CNT=ON]
04:04:09  Low ambient 19.9F < 20.0F — LOW_TEMP active
04:04:09  CNT off, FAN off
04:04:14  Y drops (thermostat)
04:05:29  Ambient 20.2F >= 20.0F — exiting LOW_TEMP → OFF (30s validation)
04:05:36  Y reactivates → FAN ON
04:05:38  STATE CHECK: FAN on in OFF — forcing OFF       ← validator vs state machine
04:06:00  State validation complete: OFF → HEAT
04:06:06  CNT activated
04:06:08  STATE CHECK: FAN off in HEAT — forcing ON       ← fixing its own damage
04:06:38  State check OK: HEAT [FAN=ON CNT=ON]
```

## Affected Code

- `src/GoodmanHP.cpp`: `validateOutputStates()` — added `_stateValidationActive`
  to skip conditions

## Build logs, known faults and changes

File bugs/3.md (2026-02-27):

# Bug #3: Config-loaded sensors marked valid on boot — stale 0.0°F triggers false LOW_TEMP protection

**Severity:** High (safety)
**Date discovered:** 2026-02-26
**Affected file:** `src/Config.cpp`
**Fixed in:** `d49d2e8` ("Fix false LOW_TEMP on boot from stale config-loaded sensor values")

---

## Summary

When the system boots, temperature sensors loaded from the SD card config are immediately marked as `valid=true` with their cached `last-value` from the previous session. If that cached value is 0 (no prior reading stored) or stale, the value 0.0°F passes the `isValid()` check and triggers `checkAmbientTemp()` — which sees 0.0°F < 20°F (or 25°F) threshold and activates LOW_TEMP protection. This shuts down CNT, turns off FAN and RV, and turns on W (auxiliary heat) — all before the first real OneWire bus read occurs ~10 seconds after boot.

## Impact

- Every reboot during an active HEAT cycle falsely triggers LOW_TEMP protection
- W (auxiliary electric heat) turns on unnecessarily for ~10 seconds until real sensor data arrives
- CNT (compressor contactor) is blocked during this window, delaying normal operation
- In the log analysis, **77 false LOW_TEMP triggers** were recorded across 263 reboots (Feb 8–26), all reading **0.0°F** as the ambient temperature
- One instance recorded **-196.6°F** (OneWire CRC error / `DEVICE_DISCONNECTED_F`) which also triggered LOW_TEMP with W turned on, self-correcting 21 seconds later when the sensor returned 185.0°F

## Incident Timeline (from log analysis)

Observed on virtually every reboot during Feb 8–15 (263 reboots total). Example sequence:

| Time | Event | Ambient Temp |
|---|---|:---:|
| Boot | Outputs verified OFF, startup lockout begins | — |
| +0s | Config loads AMBIENT_TEMP from JSON with `last-value: 0`, marks `valid=true` | 0.0°F (stale) |
| +0.5s | `update()` → `checkAmbientTemp()` sees `valid=true`, 0.0°F < threshold | 0.0°F |
| +0.5s | **LOW_TEMP activated**: CNT blocked, FAN off, RV off, W turned on | 0.0°F |
| +10s | First real OneWire bus read: AMBIENT_TEMP = 47°F | 47.0°F |
| +10s | 47°F >= threshold, LOW_TEMP cleared, W turned off | 47.0°F |

## Root Cause Analysis

### The bug: `setValid(true)` on config-loaded sensors

In `Config::loadTempConfig()` (Config.cpp:556–558), sensors loaded from the `sensors.temp` JSON section are unconditionally marked valid:

```cpp
sensor->setValue(last_value);       // Sets _valid = (value != DEVICE_DISCONNECTED_F)
sensor->setPrevious(sensor->getValue());
sensor->setValid(true);             // Overrides to valid — even if value is stale/zero
```

`setValue()` already sets `_valid = true` for any value other than `DEVICE_DISCONNECTED_F` (-196.6°F). The explicit `setValid(true)` reinforces this. A `last-value` of 0 (the JSON default when no prior reading exists) passes both checks.

### Why the protection code doesn't catch it

`checkAmbientTemp()` (GoodmanHP.cpp:251) correctly guards with:

```cpp
TempSensor* ambient = getTempSensor("AMBIENT_TEMP");
if (ambient == nullptr || !ambient->isValid()) return;
```

But since `isValid()` returns `true` for the stale config-loaded sensor, the guard passes. The 0.0°F value is then compared against the threshold and triggers LOW_TEMP.

### Why 0 is the common cached value

The `last-value` field in the config JSON is written by `saveConfiguration()` using `mp.second->getValue()`. On the very first boot (before any OneWire reading), or after a reboot where the sensor never got a valid reading before the next save, the value is 0.0 (the `TempSensor` constructor default). This 0 is persisted to JSON and reloaded on the next boot.

### All temp-based protections are affected

The same pattern applies to every temp-based protection check:
- `checkAmbientTemp()` — LOW_TEMP (0.0°F < 25°F threshold)
- `checkCompressorOverTemp()` — would NOT false-trigger (0.0°F is below the high threshold)
- `checkSuctionLowTemp()` — could false-trigger in COOL mode (0.0°F < suction threshold)

## Fix Applied

Single line change in `src/Config.cpp`:

```cpp
// Before:
sensor->setValue(last_value);
sensor->setPrevious(sensor->getValue());
sensor->setValid(true);

// After:
sensor->setValue(last_value);
sensor->setPrevious(sensor->getValue());
sensor->setValid(false);  // Not valid until first real bus read
```

Config-loaded sensors now start as `invalid`. The `isValid()` guard in all protection checks (`checkAmbientTemp`, `checkCompressorOverTemp`, `checkSuctionLowTemp`) causes them to return early without action. On the first real bus read (~10s after boot), `TempSensor::update()` sets `_valid` based on the actual reading, and protection checks resume with real data.

## Files Changed

- `src/Config.cpp` — `loadTempConfig()`: `setValid(true)` → `setValid(false)`

## How to Reproduce

1. Ensure `sensors.temp` in the SD card config has an AMBIENT_TEMP entry with `last-value: 0`
2. Set `heatpump.lowTemp.threshold` to any value above 0 (e.g., 25°F)
3. Reboot the device
4. **Before fix:** LOW_TEMP activates within 500ms of boot, W turns on, clears ~10s later when real sensor data arrives
5. **After fix:** No LOW_TEMP trigger on boot. Sensors show as `valid=false` in `/temps` for the first ~10s, then become valid with real readings

## Verification (2026-02-26)

After OTA flash, checked logs for LOW_TEMP triggers during boot:

```
[INFO ] [MAIN] OneWire: found 4 device(s) on GPIO 21
[INFO ] [MAIN] OneWire: merged 4 new sensor(s) with config
[INFO ] [HP] Low temp threshold set to 25.0F
[INFO ] [HP] GoodmanHP controller started, all outputs verified OFF, 180 sec startup lockout
[INFO ] [MAIN] Starting Main Loop
```

No "Low ambient temp" warning. All sensors transitioned to `valid=true` with real readings after the first OneWire poll:

| Sensor | Value | Valid |
|---|---|---|
| AMBIENT_TEMP | 49.55°F | true |
| COMPRESSOR_TEMP | 53.60°F | true |
| CONDENSER_TEMP | 51.80°F | true |
| LIQUID_TEMP | 57.20°F | true |
| SUCTION_TEMP | 70.81°F | true |

## Lessons Learned

- Cached/persisted sensor values should never be trusted for safety decisions — mark sensors invalid until confirmed by a real physical read
- The `isValid()` guard pattern is effective but only works if validity accurately reflects whether the value came from the physical device
- A `last-value` of 0 in config JSON is indistinguishable from a real 0°F reading — validity should be based on provenance (real read vs cached), not just value range
- This bug was latent for the entire deployment but masked after Feb 15 when the device stopped rebooting — it would resurface on any future reboot during a HEAT cycle

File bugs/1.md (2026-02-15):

# Bug #1: Defrost exit turns on CNT+FAN with Y inactive — compressor runs without indoor airflow

**Severity:** Critical (safety)
**Date discovered:** 2026-02-15
**Affected file:** `src/GoodmanHP.cpp`
**Fixed in:** `028e568` ("Fix defrost exit Y-inactive safety bug")

---

## Summary

When the thermostat satisfies (Y drops) during defrost Phase 1 or Phase 2 (before the compressor starts), a chain of bugs causes the defrost exit sequence to unconditionally turn on CNT (compressor contactor) and FAN approximately 60 seconds later — even though Y is no longer active. The heat pump runs without the indoor air handler, causing suction temperature to spike dangerously.

## Impact

- Compressor runs without indoor airflow (no heat exchange on indoor coil)
- Suction temperature climbs rapidly — peaked at **148.0°F** (8°F above the 140°F RV-fail threshold)
- Risk of compressor thermal lockout or damage
- Required manual reboot to stop

## Incident Timeline (2026-02-15)

| Time | Event | Suction Temp |
|---|---|:---:|
| 05:29:30 – 05:35:41 | Normal HEAT cycle, heat runtime accumulating | ~60°F |
| **05:35:41** | Heat runtime reaches 60 min threshold, defrost starts (Phase 1: all off) | — |
| 05:35:42 | State changed: HEAT -> DEFROST | — |
| 05:36:12 | Phase 1 complete (30s), Phase 2 starts: RV+W on, CNT waiting | — |
| **05:36:30** | **Y drops** (thermostat satisfied). Y-drop handler: RV off, W off, transition flags cleared. `_softwareDefrost` stays true (by design) | — |
| **05:36:30** | **BUG**: Same `update()` call — `checkDefrostNeeded()` sees `_softwareDefrost=true` + no transition flags. Computes `elapsed = millis() - _defrostStartTick`. `_defrostStartTick` is **0** (never set — Phase 3 never reached). `millis() - 0` >> 15 min. **False timeout fires.** | — |
| 05:36:30 | `stopSoftwareDefrost()` called — starts exit transition (`_defrostExiting=true`). Y-drop edge already processed, so this is never caught | — |
| 05:37:01 | Exit Phase 1 complete (30s): RV off, W off (already off) | ~60°F |
| **05:37:31** | **Exit Phase 2 complete: CNT ON, FAN ON** — no Y-active check! | 104°F |
| 05:37:34 | CNT 3s delay complete, compressor starts | — |
| 05:39:16 | Suction temp climbing rapidly (no indoor airflow) | 104°F |
| 05:40:16 | — | 120.5°F |
| 05:40:46 | — | 128.5°F |
| 05:41:46 | — | 137.5°F |
| **05:42:16** | **Suction crosses 140°F threshold** (not caught — state is OFF, not DEFROST) | **140.0°F** |
| 05:43:17 | — | **146.8°F** |
| 05:44:16 | — | **148.0°F** (peak) |
| **05:45:15** | Manual reboot via HTTPS | 146.9°F |
| 05:45:20 | System reboots, all outputs verified OFF | — |
| 05:48:19 | Startup lockout complete (180s) | — |
| 05:53:00 | Next normal HEAT cycle begins | — |

## Root Cause Analysis

Three interacting bugs in `checkDefrostNeeded()` and `stopSoftwareDefrost()`:

### Bug 1: `_defrostStartTick` is 0 when defrost never reaches Phase 3

`_defrostStartTick` is initialized to 0 in the constructor and only set at `GoodmanHP.cpp:973` when Phase 2 completes (Phase 3 begins):

```cpp
_defrostStartTick = now;  // Only set here — Phase 3 start
```

If Y drops during Phase 1 or Phase 2 (before Phase 3), `_defrostStartTick` remains **0**. When the Y-drop handler clears the transition flags (`_defrostTransition = false`, `_defrostCntPending = false`) but leaves `_softwareDefrost = true`, `checkDefrostNeeded()` falls through to the active defrost check:

```cpp
if (_softwareDefrost) {
    uint32_t elapsed = now - _defrostStartTick;  // now - 0 = huge number
    // ...
    if (elapsed >= DEFROST_TIMEOUT_MS) {          // Always true!
        stopSoftwareDefrost();                     // False timeout
    }
}
```

### Bug 2: `stopSoftwareDefrost()` starts exit transition without checking Y

`stopSoftwareDefrost()` unconditionally sets `_defrostExiting = true` and begins the 60-second exit sequence, even when called with Y inactive:

```cpp
void GoodmanHP::stopSoftwareDefrost() {
    // No Y-active check!
    _defrostExiting = true;
    _defrostTransition = true;
    _defrostTransitionStart = millis();
    // ...
}
```

### Bug 3: Exit Phase 2 completion turns on CNT+FAN without checking Y

The exit Phase 2 handler unconditionally turns on outputs:

```cpp
if (_defrostCntPending && _defrostExiting) {
    if (now - _defrostCntPendingStart >= _cntShortCycleMs) {
        // No Y-active check!
        cnt->turnOn();    // Compressor ON with Y inactive
        fan->turnOn();    // Outdoor fan ON with Y inactive
    }
}
```

### Bug 4: Ordering issue — `_defrostExiting` set after Y-drop edge already handled

The `_defrostExiting` cleanup in `checkYAndActivateCNT()` only runs inside the `!yActive && _yWasActive` block (the Y-drop edge). Since `_defrostExiting` is set by `stopSoftwareDefrost()` in `checkDefrostNeeded()` — which runs **after** `checkYAndActivateCNT()` in the same `update()` call — the Y-drop edge has already been consumed and can't catch it.

Execution order within `update()`:
1. `checkYAndActivateCNT()` — Y-drop edge fires, `_defrostExiting` is false, not caught
2. `updateState()` — State transitions DEFROST -> OFF
3. `checkDefrostNeeded()` — False timeout fires, sets `_defrostExiting = true` (too late)

### Why high suction temp check didn't trigger

The `checkHighSuctionTemp()` function only monitors suction temperature during active defrost. After the false timeout, `_softwareDefrost` was cleared and state was OFF. The 140°F threshold was crossed at 05:42:16 but not detected because the system was not in DEFROST state.

## Fix Applied

Defense-in-depth approach with 4 layers of protection in `src/GoodmanHP.cpp`:

### 1. Y-active safety gate at top of `checkDefrostNeeded()`

Added a master guard that cancels any active defrost/exit sequence when Y is not active:

```cpp
InputPin* yPin = getInput("Y");
bool yActive = (yPin != nullptr && yPin->isActive());
if (!yActive && (_defrostExiting || _defrostTransition || _defrostCntPending)) {
    // Turn all outputs OFF, clear all transition flags
    Log.warn("HP", "Y inactive during defrost/exit sequence, all outputs OFF");
    _defrostExiting = false;
    _defrostTransition = false;
    _defrostCntPending = false;
    return;
}
```

This catches the ordering issue (Bug 4) — even if `_defrostExiting` is set after the Y-drop edge, the next `update()` call will catch and cancel it.

### 2. `_defrostStartTick == 0` guard

Prevents false timeout when defrost never reached Phase 3:

```cpp
if (_softwareDefrost) {
    if (_defrostStartTick == 0) {
        return;  // Not yet in active phase, don't check timeout
    }
    // ... existing timeout/exit logic
}
```

### 3. Y-active check in `stopSoftwareDefrost()`

If Y is inactive when defrost ends, clean up flags without starting exit transition:

```cpp
InputPin* y = getInput("Y");
if (y == nullptr || !y->isActive()) {
    Log.info("HP", "Defrost stopped (Y inactive), no exit transition");
    _softwareDefrost = false;
    _defrostExiting = false;
    _defrostTransition = false;
    _defrostCntPending = false;
    // ... cleanup without starting exit
    return;
}
```

### 4. Reset `_defrostStartTick` on defrost stop

Prevents stale tick values from carrying over to future defrost cycles:

```cpp
_defrostStartTick = 0;
```

## Files Changed

- `src/GoodmanHP.cpp` — `checkDefrostNeeded()`, `stopSoftwareDefrost()`

## How to Reproduce

1. Set `heatRuntimeThresholdMs` to a low value (e.g., 60 min) so defrost triggers frequently
2. Let the heat pump accumulate runtime across multiple short HEAT cycles
3. When defrost starts (Phase 1 or Phase 2), have the thermostat satisfy (Y drops)
4. **Before fix:** CNT+FAN will turn on ~60s after Y drops, running the compressor without indoor airflow
5. **After fix:** All outputs stay OFF, `_softwareDefrost` flag preserved for resume on next Y activation

## Lessons Learned

- Uninitialized tick values (default 0) can cause `millis() - 0` overflow calculations to silently pass timeout checks
- Output activation functions should always verify the precondition (Y active) before turning on safety-critical outputs like the compressor
- When multiple handlers run in sequence within the same execution cycle, flags set by later handlers may not be caught by earlier handlers — a top-of-function safety gate is more robust than relying on edge detection

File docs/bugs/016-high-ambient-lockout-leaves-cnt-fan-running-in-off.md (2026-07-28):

# BUG-016: High-ambient-HEAT lockout set state to OFF but left CNT/FAN (and RV) running

**Date**: 2026-07-28
**Severity**: High (compressor kept running against the system's own OFF decision, with no self-correction)
**Status**: Fixed, verified live on bench (`192.168.1.125`); not yet deployed to production
**Affected versions**: `45e2696` (introduced the high-ambient-HEAT lockout) through `8a52a19`
**Fixed in**: pending commit (this session)

## Symptom

On the bench controller, with `Y` active (a heat call) and ambient above the
`highAmbientLockout` threshold (default 70°F), `/state` reported
`"state": "OFF"` while `CNT`, `FAN`, and (transiently) `RV` all showed `true`
— the compressor and fan kept running for minutes with no sign of
self-correcting, even though the state machine had already decided the
system should be off. Reproduced live by dropping `O` while ambient was
above the lockout threshold — exactly the scenario the lockout exists to
prevent from running as HEAT.

`/state` also showed `"stateValidating": true, "stateValidationRemainSec": 0`
holding indefinitely (well past the configured 30s window), instead of
clearing.

## Root Cause

Three independent gaps, all in `src/GoodmanHP.cpp`, that only compound into
a visible problem once something (the high-ambient-HEAT lockout, added in
`45e2696`) can force `_state = State::OFF` while `Y` is still active. Before
that feature existed, `State::OFF` only ever happened with `Y` inactive, so
none of these had a chance to matter — `checkYAndActivateCNT()` never tries
to energize anything when `Y` is off, so a disabled safety net was harmless.

### 1. The OFF-transition never told CNT/FAN to turn off

`updateState()`'s per-transition output-control block (lines ~1088-1189)
explicitly manages RV (`safeRvOff()`) and W for every new state, and CNT+FAN
as the first step of the COOL/HEAT/DEFROST *sequenced* transitions — but
`State::OFF` has no sequenced transition of its own, so nothing in that
block ever told CNT or FAN to turn off when landing in OFF. They simply kept
whatever state they were in from the prior COOL/HEAT run.

### 2. `validateOutputStates()`'s corrective sweep never got a chance to run

That function is the documented safety net — it runs every 10s and has a
table-driven expected-output row for every state, including `OFF`
(`expFAN=0, expCNT=0, expRV=0, expW=0`) with auto-correction. It should have
caught gap #1 within 10 seconds. But it unconditionally skips its entire
check whenever `_stateValidationActive` is true — and that flag is only
ever cleared inside `canTransitionToNormalState()`, which `updateState()`
only calls when *attempting* a transition to HEAT/COOL/DEFROST
(`newState != State::OFF && newState != State::ERROR`). Transitions into
OFF/ERROR are deliberately high-priority and bypass that gate on *entry* —
but `startStateValidation()` still arms the flag on *every* transition,
including into OFF. With `Y` active and ambient staying above threshold,
`updateState()` keeps recomputing `OFF` on every tick and never attempts a
HEAT/COOL/DEFROST transition again, so `canTransitionToNormalState()` is
never called, and the flag — and the safety net it disables — stays stuck
forever.

### 3. `checkYAndActivateCNT()` doesn't know the lockout exists

This is a second, independent control path (runs *before* `updateState()`
in `update()`, `GoodmanHP.cpp:567` vs `570`) that energizes CNT/FAN purely
off `isYActive()`, gated by a hardcoded list of fault flags
(`_lpsFault`, `_lowTemp`, `_fanFault`, etc.) — a list that has no entry for
`_highAmbientHeatLockout`. The Y-edge handler inside the same function also
unconditionally turns FAN on the moment `Y` becomes active (gated only on
`_state != State::DEFROST`). Neither path checks whether the state machine
has actually decided to run. Fixing #1 and #2 alone stops the *steady-state*
symptom but not this: on every Y-active cycle, this function would
re-energize CNT/FAN moments after the OFF-transition or validator turned
them off, fighting the other two fixes indefinitely.

## Fix

- **`updateState()`** (OFF-transition block): added explicit `CNT`/`FAN`
  shutdown when `newState == State::OFF`, matching the pattern already used
  for `W`.
- **`validateOutputStates()`**: added a self-expiry check —
  `_stateValidationActive` now clears itself once `_stateValidationMs` has
  elapsed, independent of whether another transition attempt happens to
  call `canTransitionToNormalState()`. Preserves the original "hold before
  allowing another normal-priority change" semantics (still time-gated
  the same way) while guaranteeing the corrective sweep can't stay
  disabled indefinitely just because the system is parked in OFF/ERROR.
- **`checkYAndActivateCNT()`**: added `_state == State::OFF` to the
  fault-flag blacklist that blocks CNT activation, and added the same
  check to the Y-edge FAN-on trigger. `update()` calls `updateState()`
  immediately after this function on every tick, so `_state` reflects the
  previous tick's authoritative decision — using it as a gate doesn't
  introduce a race against legitimate HEAT/COOL activation, since by the
  time CNT would actually try to activate (after the 30s/5min short-cycle
  timers), `_state` has long since settled to whatever `updateState()`
  actually decided.

## Verification (bench, `192.168.1.125`)

Reproduced live: `Y` active, `O` dropped, ambient 74°F (> 70°F lockout).

| | Before fix | After fix |
|---|---|---|
| `state` | `OFF` | `OFF` |
| `stateValidating` | stuck `true` (4+ min observed) | `false` within 30s, self-clears |
| `CNT` / `FAN` / `RV` | all `true`, indefinitely | all `false`, held steady 40+s across 8 polls |

Deployed via OTA (`/update` + `/apply`); device came back with a clean
`SW_RESET`, `crashBootCount: 0`, `safeMode: false`, all outputs verified OFF
at boot. Log confirmed no fight between `checkYAndActivateCNT()` and the
OFF-transition/validator after the fix — CNT/FAN simply stayed off.

**Not yet deployed to production** (`192.168.0.49`) — bench-only as of this
report.

## Affected Code

- `src/GoodmanHP.cpp`:
  - `updateState()` — added CNT/FAN shutdown block for `newState == State::OFF`
  - `validateOutputStates()` — added `_stateValidationActive` self-expiry
  - `checkYAndActivateCNT()` — added `_state == State::OFF` gate to both the
    CNT-activation fault blacklist and the Y-edge FAN-on trigger

## Lessons Learned

- **A state label and the outputs it implies can drift apart the moment a
  new code path can *force* the label without going through every place
  that reacts to it.** The high-ambient-HEAT lockout only touched
  `updateState()`'s `newState` computation — it had no way to know that two
  other functions (`checkYAndActivateCNT()`, and `updateState()`'s own
  transition-output block) each independently assumed "OFF" was a state
  that could only be reached with `Y` inactive, and hardcoded their safety
  logic around that assumption instead of the general case.
- **A safety net that can be permanently disabled by the exact condition
  it exists to catch is not a safety net.** `validateOutputStates()`'s
  `_stateValidationActive` gate was designed to prevent it from
  double-correcting mid-transition — reasonable in isolation — but nothing
  guaranteed the gate would ever re-open once the system settled into a
  state that never attempts another transition. Any "pause the checker"
  flag needs its own unconditional expiry, not just an expiry that's
  contingent on something else happening to try again.
- **Two independent control paths driving the same output invite exactly
  this kind of bug.** `checkYAndActivateCNT()` and `updateState()` both
  decide when CNT/FAN should run, from different trigger conditions
  (`isYActive()` directly vs. the computed state machine result), and nothing
  enforced that they agree. Gating the independent path on the
  authoritative one's own decision (`_state == State::OFF`) is the fix here,
  but the deeper lesson is to be suspicious whenever the same relay has
  more than one function that can turn it on.
- **Reproduce the exact scenario the user is testing, live, before writing
  up the fix.** The first two fixes alone looked complete on paper and
  would have shipped without catching gap #3 — only re-running the OTA
  cycle and polling `/state` against the same "Y active, O dropped, ambient
  above threshold" test the user was already running caught that CNT/FAN
  were still coming back on.

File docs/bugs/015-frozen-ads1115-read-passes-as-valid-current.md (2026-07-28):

# BUG-015: Loose ADS1115 connection froze current readings that still passed as `valid` — false FAN_FAULT trips shut down production compressor every ~3.5 min

**Date**: 2026-07-28
**Severity**: High (production equipment actively short-cycled by a false safety trip)
**Status**: Mitigated on production (physical reseat); **root-cause code gap still open** — no fix applied yet
**Affected versions**: all versions through `45e2696` (current as of this report), including both the pre- and post-BUG-014 `CurrentSensor` implementations
**Board**: production controller, `192.168.0.49`

## Symptom

Production controller was latching `ERROR` state roughly every 3.5 minutes
while in `COOL` mode with the compressor and fan both confirmed physically
running by direct observation. `/log` showed a clean, repeating
`checkFanFault()` trip cycle:

```
FAN_FAULT: FAN current low (0.00A < 0.30A) while CNT on, FAN pin already ON — watching 20s
FAN_FAULT: still low current 0.00A at ...ms/20000ms of grace window
FAN_FAULT: TRIP — FAN current 0.00A < 0.30A for 20000ms ... — shutting down compressor
FAN_FAULT: CNT shut down after ~18s of runtime (no airflow, fanAmps=0.00)
FAN_FAULT: ENTER ERROR state for 3 min lockout
```

`/state` confirmed both `COMPRESSOR_CURRENT` and `FAN_CURRENT` reading a
flat `0.0A` the entire time, despite the compressor drawing its normal
~7A and the fan running. The OLED display had also stopped updating, and
`LIQUID_TEMP` (MCP9600 I2C thermocouple fallback) had been frozen at
exactly `32.0°F` all session — both suggestive of a shared-I2C-bus problem,
though the MCP9600 turned out to be a separate, likely pre-existing issue
(see Investigation).

The user physically reseated the ADS1115 breakout board; both current
channels immediately began reading live, moving values again
(`COMPRESSOR_CURRENT` ~7.0-7.2A, `FAN_CURRENT` ~0.8A across successive
polls), and the `ERROR` cycling stopped.

## Root Cause

**A loose/marginal physical connection to the ADS1115 board**, combined
with a library-level gap: `Adafruit_ADS1X15::readRegister()` /
`writeRegister()` (vendored, unmodified — `.pio/libdeps/*/Adafruit
ADS1X15/Adafruit_ADS1X15.cpp`) call `m_i2c_dev->write()` /
`m_i2c_dev->read()` and **discard the returned success/failure status**:

```cpp
uint16_t Adafruit_ADS1X15::readRegister(uint8_t reg) {
  buffer[0] = reg;
  m_i2c_dev->write(buffer, 1);
  m_i2c_dev->read(buffer, 2);
  return ((buffer[0] << 8) | buffer[1]);
}
```

When the physical connection is marginal, these I2C transactions fail, but
`buffer` simply keeps whatever it held from the last successful read —
`readRegister()` returns **the same stale, non-zero raw ADC code every
single call**, with no exception, no error return, nothing to distinguish
it from a genuine fresh reading.

This defeated the one guard `CurrentSensor::tick()` (added in BUG-014) does
have against bad I2C data:

```cpp
// Reject "all zeros" reads (I2C NACK / bus contention signature) ...
if (_nonZeroCount == 0) {
    _valid = false;
    ...
}
```

A frozen-but-nonzero raw value has `_nonZeroCount > 0` (passes the guard),
but because all 60 accumulated samples are *identical*, `variance =
mean(v²) - mean(v)² = 0` exactly — so `_rmsAmps` comes out to precisely
`0.00A` and `isValid()` is `true`. `checkFanFault()` (`src/GoodmanHP.cpp:411`)
only skips its trip logic when `!fanCur->isValid()`; a validly-flagged
`0.00A` reading looks identical to a real "fan isn't moving air" fault, so
the safety logic did exactly what it's designed to do — it just did it on
corrupted sensor data instead of a real fault.

This is a **latent gap that predates BUG-014**: the old blocking
`readRMS()` used the same `readRegister()`/`writeRegister()` calls and
would have frozen identically under a loose connection. BUG-014's
non-blocking rewrite changed *how* samples are collected, not whether a
frozen I2C read is detected — so tonight's `CurrentSensor` changes are not
the cause here, they just happened to be the most recently-touched code
in the vicinity.

## Investigation notes (ruled out / inconclusive)

- **MCP9600 (`LIQUID_TEMP`) frozen at exactly 32.0°F**: unlike the ADS1115
  driver, `TempSensor::update()`'s MCP9600 path (`src/TempSensor.cpp:60-104`)
  uses raw `Wire` calls with explicit error checking
  (`Wire.endTransmission(false)` return code, `Wire.requestFrom()` byte
  count). Both were succeeding (no "MCP9600 write failed"/"read short"
  messages), meaning the MCP9600 itself was ACKing and returning genuine
  register data — just a hot-junction register reading of raw `0` (0°C)
  every time. This is **not proof of a bus-wide lockup**; it's a separate,
  likely pre-existing MCP9600/thermocouple issue (open thermocouple lead,
  or the chip itself) that happened to be present throughout this
  session and deserves its own look, but isn't part of this bug's root
  cause. Note also that this driver's error messages go to `Serial.printf()`,
  **not** the `Logger`/ring-buffer — they would not have shown up in a
  remote `/log` fetch even if they had fired, which is why they didn't
  appear during remote diagnosis.
- **OLED going dark**: plausibly the same physical jostle affected a
  nearby connector/header shared with the ADS1115 board; not independently
  confirmed, and the SSD1306 library path wasn't audited for the same
  ignore-the-I2C-error pattern as part of this report.
- **A current "spike" observed 8:30-9:00 AM** on both channels, followed by
  the flatline, is consistent with the connection going from fully-seated
  to intermittent (noisy contact) to fully stuck-stale over that window,
  though the exact failure progression wasn't captured.

## Fix Applied

**Physical only**: reseating the ADS1115 board resolved the immediate
production hazard. No code was changed.

## Fix Not Yet Applied (open)

`CurrentSensor::tick()` should detect a frozen/stale read the same way it
already detects an all-zero read, since both are I2C-failure signatures
that can otherwise pass as a legitimate low-current reading:

- Track the raw ADC value (or a hash/sum of the 60-sample window) across
  consecutive sampling rounds per sensor.
- If the raw values are bit-for-bit identical across N consecutive rounds
  (e.g. 3), mark `_valid = false` and log `"%s read invalid: frozen value
  (I2C stale/disconnected?)"` instead of publishing a fake `0.00A`.
- This gives `checkFanFault()` (and the overcurrent/locked-rotor logic,
  which shares the same `isValid()` gate) the same protection against a
  frozen sensor that it already has against a dead one.

This is a firmware-side mitigation for a hardware-connection problem — it
won't fix a loose connector, but it will stop a loose connector from
silently masquerading as "the fan actually stopped" and shutting down the
compressor.

## Affected Code

- `include/CurrentSensor.h` / `src/CurrentSensor.cpp` — `tick()`'s
  validity check doesn't catch a frozen (non-zero, no-variance) read;
  needs the stale-value detector described above.
- `.pio/libdeps/*/Adafruit ADS1X15/Adafruit_ADS1X15.cpp` (vendored
  library, not project code) — `readRegister()`/`writeRegister()` ignore
  `Adafruit_BusIO_Device::write()`/`read()` return values entirely. Not
  something to patch in a vendored library; the defense belongs in
  `CurrentSensor::tick()` instead.
- `src/GoodmanHP.cpp:411` (`checkFanFault()`) — correctly skips its trip
  logic on `!isValid()` today; will automatically benefit once `isValid()`
  can distinguish frozen from fresh.

## Lessons Learned

- **"Valid but wrong" is a worse failure mode than "invalid."** The
  existing all-zero guard proves the team already knew I2C reads could
  fail silently — but a stuck-nonzero failure slipped through the same
  gap because the guard checked "is the raw value zero," not "did the
  raw value actually change." Any check written against one specific
  failure signature should be paired with the question "what if this
  fails a different way?"
- **A physical fix and a code fix are both real fixes, and neither
  substitutes for the other.** Reseating the board stopped tonight's harm
  immediately and correctly; it doesn't mean the software gap that let a
  frozen sensor drive a safety shutdown should stay open; the same loose
  connection (or a similar one) will recur eventually.
- **Debug logging that only reaches `Serial` is invisible during remote
  diagnosis.** The MCP9600 path's error handling is more careful than the
  ADS1115 path's (it checks return codes) but its failures would never
  have been seen in this investigation because they don't go through
  `Logger`. Worth routing all I2C-adjacent error paths through the same
  ring-buffer-backed logger the rest of the system uses.

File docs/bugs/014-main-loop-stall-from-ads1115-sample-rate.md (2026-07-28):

# BUG-014: Main loop stalled ~1s per pass — blocking ADS1115 current-sensor reads

**Date**: 2026-07-27
**Severity**: High
**Status**: Fixed
**Affected versions**: `f9f836a` through `45e2696` (~16 days in production)
**Fixed in**: `9870f65` (loop stall + CPU load metric), `3c202f7` (accuracy regression from the interim fix), `5c5cbf5` (current-monitoring config save + calibration tool); calibrated `compressorCtRatio`/`fanCtRatio` values applied live via the device config (not a code change)

## Symptom

The dashboard's "CPU 0" and "CPU 1" tiles always read `0%`, regardless of
system state or load. Investigating that cosmetic issue led to a much more
serious discovery: the Arduino main loop (`loop()` in `src/main.cpp`) was
completing only **~1 iteration per second**, instead of the several hundred
per second a cooperative-scheduler design like this expects.

## Impact

Every task driven off `loop()` → `ts.execute()` was running far behind its
configured cadence for the entire ~16 days this was live:

- `_tGetInputs` (500ms input-debounce validation) — running at roughly half
  its intended rate
- CNT short-cycle protection, defrost phase transition timers (`_rvShortCycleMs`,
  `_cntShortCycleMs`) — all timed off `millis()` checks inside tasks that
  could only be evaluated once a second instead of continuously
- WebSocket log streaming, HTTP/API responsiveness — degraded, since the
  main loop (not AsyncTCP) is where scheduled work executes
- Masked entirely from monitoring, because the CPU-load metric that should
  have shown this (a pegged-high core 1) was itself broken and always
  reported `0%` — see Root Cause #1

No safety fault fired because nothing in the state machine checks its own
scheduling latency; the system kept functioning, just with much coarser
timing precision than intended on every sub-second protection.

## Root Cause

Two independent problems, discovered in sequence:

### 1. CPU load metric always read 0% (masked the real bug)

`main.cpp` measured per-core load via FreeRTOS idle hooks: accumulate
microseconds between consecutive idle-task invocations, `load = 100 - idle%`.
This had already been "fixed" twice before (see git history on
`idleHookCore0/1`) — an earlier version starved the idle hooks under load
(read 90%+ always), and the fix for that added an unconditional
`vTaskDelay(1)` at the end of every `loop()` pass specifically so idle hooks
could fire on both cores.

That delay overcorrected: since real work per pass is normally much shorter
than one FreeRTOS tick, the forced 1-tick sleep dominated the loop period.
The idle-hook accumulator couldn't distinguish "genuinely idle" from "idle
because we just forced ourselves to sleep," so it pegged at the 0%-load
reading (100% "idle") every single second — including during this incident,
when the loop was in fact almost fully consumed by real work.

### 2. `CurrentSensor::readRMS()` blocked the loop for ~900ms/sec

`src/CurrentSensor.cpp` samples the ADS1115 60 times per current sensor to
compute RMS current (`COMPRESSOR_CURRENT`, `FAN_CURRENT` — 2 sensors on this
deployment), called once per second via `tReadCurrent`. The code's own
comment claimed:

> "ADS1115 at 860 SPS in continuous mode gives ~1.16ms per sample"

but `readRMS()` never called `ads->setDataRate(...)`, so it silently ran at
the Adafruit_ADS1X15 library's **default of 128 SPS** — roughly 7.8ms per
blocking one-shot sample (`readADC_Differential_0_1/2_3()` busy-polls
`conversionComplete()` until the conversion finishes), not 1.16ms.

60 samples × ~7.8ms × 2 sensors ≈ 936ms — called synchronously, once per
second, from inside `ts.execute()` on the Arduino loop task. That's why
`loop()` could only complete ~1 pass/sec: nearly the entire second was
spent blocked inside ADC polling for two current sensors.

## Detection

Investigating why the dashboard showed a suspicious "ESP32 internal temp"
fallback value led to a broader look at the dashboard's system-stats tile,
which turned up `CPU 0`/`CPU 1` both reading exactly `0%` — live-verified
against the production device (`/state` polled repeatedly, never moved off
`0`). Tracing the CPU-load code through its git history (three prior
attempts at the same idle-hook approach) pointed at the `vTaskDelay(1)`
added in a previous fix as the likely culprit.

Rewriting core 1's measurement to use direct busy-time accounting (timestamp
real work instead of relying on idle hooks) produced a new, unexpected
reading: ~99% load, sustained. That was surprising enough on its own —
walking a ~15-task scheduler list should take microseconds, not most of a
second — to warrant one more diagnostic: a `loopItersPerSec` counter
(incremented once per `loop()` pass, exposed via `/heap`). That counter
read exactly **1** on the live device, which pointed directly at whatever
single per-second task was blocking: `tReadCurrent`, and from there,
`CurrentSensor::readRMS()`'s undeclared sample rate.

## Fix attempt #1 (`9870f65`) — bumped to 860 SPS, caused an accuracy regression

The first fix was minimal: explicitly call `ads->setDataRate(RATE_ADS1115_860SPS)`,
matching what the code comment already assumed. At 860 SPS the same 60-sample
blocking read drops from ~936ms to ~140ms for both sensors combined — loop
iteration rate went from ~1/sec to ~660+/sec, and `cpuLoad1` (now measured
correctly) settled at a believable ~45%.

This looked like a full fix until a clamp meter was put on the compressor and
fan leads next to the board and compared against the live readings at the
same moment:

| | Device (860 SPS) | Clamp meter | Error |
|---|---|---|---|
| Compressor | ~8.16A | 7.14A | **+1.02A (+14.3%)** |
| Fan | 0.9A | 0.54A | **+0.36A (+66.7%)** |

Both channels read high, and the fan channel — the smaller signal — was hit
much harder proportionally. That pattern (same sensor type, same `ctRatio`,
very different % error) doesn't fit a simple ratio/calibration problem; it
fits a noise floor that's a fixed fraction of full scale regardless of the
actual signal. The ADS1115's internal digital filter bandwidth widens as
data rate increases, so 860 SPS lets more line noise and motor/switching
harmonics through into each individual sample than 128 SPS does — inflating
the RMS calculation, and inflating it worst on the channel where the noise
is a bigger fraction of the real signal.

**This was a real regression, live on production current-sensing hardware
that feeds overcurrent and locked-rotor safety logic**, introduced by fix
attempt #1 in the course of fixing the loop stall.

## Fix attempt #2 (`3c202f7`) — non-blocking sampling, back to 128 SPS

Bumping the data rate traded accuracy for speed on a single knob. The actual
problem was never the *sample rate* — it was that the code sampled the ADC
*synchronously*, busy-waiting through all 60 conversions in one call. The
correct fix decouples the two: keep 128 SPS's better accuracy, but stop
blocking the loop while waiting for each conversion.

`CurrentSensor` was converted from a single blocking `readRMS()` call into a
non-blocking state machine:

- `beginSample(ads)` — resets accumulators, sets gain + 128 SPS, starts one
  ADS1115 one-shot conversion (`startADCReading(mux, /*continuous=*/false)`)
  and returns immediately.
- `tick(ads)` — call every `loop()` pass. Checks `ads->conversionComplete()`;
  if not ready, returns `false` and does nothing else this pass (no busy
  wait — other scheduler work runs in the gap). If ready, accumulates the
  sample and either starts the next conversion (still 59 to go) or, once all
  60 are in, runs the same AC-RMS math as before and returns `true`.

Since the ADS1115 is one shared I2C ADC, only one sensor can be
mid-acquisition at a time. `GoodmanHP` round-robins:

- `readCurrentSensors()` (still triggered once/sec by `tReadCurrent`) now
  only *starts* a round — `beginSample()` on the first sensor.
- `tickCurrentSensors()` — called every `loop()` pass — advances whichever
  sensor is currently converting. When a sensor's `tick()` returns `true`,
  its `checkProtections()` runs and the round-robin moves to the next
  sensor; when the last one finishes, sampling goes idle until the next
  1-second trigger.

Net effect: a ~7.8ms conversion no longer blocks anything — it's spread
across however many `loop()` passes happen to occur while it completes.

Re-verified against the clamp meter after this fix:

| | Device (128 SPS, non-blocking) | Clamp meter | Error |
|---|---|---|---|
| Fan | 0.6A | 0.54A | +0.06A (+11%) |

Fan-channel error dropped from +67% (860 SPS) to +11% (128 SPS,
non-blocking) — within plausible clamp-meter/CT tolerance. (Compressor
current wasn't directly comparable at this checkpoint since real compressor
draw had already shifted between checks — 5.4A vs. the earlier 7.14A/8.16A
reading — but the fan-channel result alone confirms the noise-bandwidth
hypothesis and that reverting to 128 SPS recovers the original accuracy.)

## Fix attempt #3 (config, not code) — the "within tolerance" 128 SPS reading was still a real ~20-25% calibration gap

The +11% fan-channel reading above was taken from a single pair of
readings at two different points in time (clamp meter, then device) and
written off as "close enough." Three more clamp-meter sessions later the
same evening, taken as close to simultaneously as possible with the
compressor in steady, continuous operation, told a different story —
both channels were **consistently low**, not high, and consistently by a
similar margin:

| Session | Compressor (device / clamp) | Error | Fan (device / clamp) | Error |
|---|---|---|---|---|
| 1 | 5.5A / 7.19A | −23.5% | 0.6A / 0.75A | −20% |
| 2 | ~5.4A / 7.26A | ~−25% | ~0.6A / 0.768A | ~−22% |
| 3 | 5.3A / 7.03A | −24.6% | 0.6A / 0.767A | −21.8% |

Ambient temperature (and therefore heat load) affects compressor current
but not fan current much — fan current tracking a tight, consistent error
band across all three sessions (independent of the compressor swinging
with load) was the tell that this was a real, fixable calibration
constant, not noise or a timing mismatch. Averaging the device/clamp
ratios across all three sessions gave corrected `ctRatio` targets:
`compressorCtRatio` 30.0 → **39.7**, `fanCtRatio` 30.0 → **37.7**. Both
channels needing a similar ~25-30% correction independently points at one
shared root cause (most likely the assumed ADC LSB/reference-voltage
conversion constant, `0.0000625V/bit` at `GAIN_TWO`, being off for this
specific board) rather than two coincidentally similar per-sensor
miscalibrations — though the fix (correcting `ctRatio` per channel) is
correct regardless of which it is.

**Blocker**: there was no way to actually persist a `ctRatio` change on
the device. `config.html`'s "Current Monitoring" fieldset has UI for
`compressorCtRatio`, `fanCtRatio`, `crankcaseCtRatio`, burden resistors,
overcurrent thresholds, and locked-rotor threshold — but `POST /config`
never read any of them, so saves silently did nothing, and `GET
/config?format=json` never exposed them either, so the form always
loaded blank. Separately, `compressorCtRatio`/`fanCtRatio` were `<select>`
dropdowns limited to commercial SCT-013-xxx presets (5/10/15/20/25/30/50/100),
which can't hold a calibrated value like 39.7 at all.

Fixed in `5c5cbf5`:

- Wired up both sides of `/config` for the whole current-monitoring
  fieldset, applying live values through the existing `CurrentSensor`
  setters (`setCtRatio()`, `setOvercurrentThreshold()`, etc.) the same
  way every other live setting in the handler works.
- Converted the CT ratio fields from `<select>` to free-form
  `<input type=number>`, keeping the standard presets as a `<datalist>`
  for quick-pick convenience instead of a hard constraint.
- Added a 3-point calibration tool to the config page: capture the live
  device reading, enter the simultaneous clamp-meter reading, repeat 3x,
  and it averages the device/clamp ratio to compute and fill in a
  corrected `ctRatio` per channel — so this doesn't require a full manual
  investigation to redo next time.
- Also bumped `/www/upload`'s hardcoded 50KB cap to 200KB — `config.html`
  (57KB before this change, 61KB after) already exceeded the old 50KB
  limit, so this SD-card page-upload path had likely been silently broken
  independent of anything else in this report.

`compressorCtRatio=39.7` / `fanCtRatio=37.7` were then applied via the
now-working `POST /config` and persisted to `config.txt` on the SD card —
this part isn't a code change, so it isn't in a commit; it's live device
configuration, and would need to be reapplied (or re-derived with the
calibration tool) if the SD card config is ever reset.

Final verification, same evening, device polled ~3 minutes after a fresh
clamp reading with the compressor in the same steady run:

| | Device | Clamp meter | Error |
|---|---|---|---|
| Compressor | 7.1A | 7.01A | **+0.09A (+1.3%)** |
| Fan | 0.8A | 0.743A | **+0.057A (+7.7%)** |

Both channels now well within normal clamp-meter/CT tolerance.

## Affected Code

- `src/main.cpp`: `idleHookCore0/1` → single `idleHookCore0` +
  `_busyUsCore1` busy-time accounting, `onCalcCpuLoad()`, `loop()`,
  `_loopIterCount`/`getLoopItersPerSec()`, `hpController.tickCurrentSensors()`
  call added to `loop()`
- `src/WebHandler.cpp`: `GET /heap` — added `loopItersPerSec` field
- `include/CurrentSensor.h` / `src/CurrentSensor.cpp`: `readRMS()` replaced
  with `beginSample()` + `tick()` non-blocking state machine (128 SPS)
- `include/GoodmanHP.h` / `src/GoodmanHP.cpp`: `readCurrentSensors()`
  changed to start-a-round semantics; new `tickCurrentSensors()` round-robin
  driver, `_currentSampleIt`/`_currentSamplingActive` state
- `src/WebHandler.cpp`: `POST /config` and `GET /config?format=json` — wired
  up `compressorCtRatio`, `fanCtRatio`, `crankcaseCtRatio`,
  `compressorBurdenOhms`, `fanBurdenOhms`, `crankcaseBurdenOhms`,
  `crankcaseExpectedAmps`, `compressorOvercurrentAmps`, `fanOvercurrentAmps`,
  `overcurrentDelaySec`, `lockedRotorThreshold`, `lockedRotorTimeoutSec`;
  `/www/upload` size cap 50KB → 200KB
- `data/www/config.html`: CT ratio fields `<select>` → `<input type=number>`
  with `<datalist>` presets; new 3-point calibration tool
  (`toggleCtCalib()`, `captureCtRow()`, `computeCtCalibration()`)

## Verification (production, `192.168.0.49`)

| | Before | After busy-time fix (revealed the stall) | Fix #1: 860 SPS (blocking) | Fix #2: 128 SPS (non-blocking) | Fix #3: calibrated ctRatio |
|---|---|---|---|---|---|
| `loopItersPerSec` | not measured | **1** | ~660–673 | ~390–840 (varies with real workload) | ~390–840 |
| `cpuLoad1` | `0` (always, artifact) | ~99% (real, caused by the stall) | settles ~45% | settles ~38–42% | ~38–42% |
| `cpuLoad0` | `0` | `0` | ~3–6% | ~2–3% | ~2–3% |
| Current-sensor accuracy vs. clamp meter | not checked | not checked | fan +67% high | fan +11% high (compressor unverified) | compressor +1.3%, fan +7.7% |

Each stage deployed via OTA (`/update` + `/apply`, which auto-backs up the
running firmware first). Device came back with a clean `SW_RESET`,
`crashBootCount:0`, `safeMode:false` after every deploy.

## Lessons Learned

- **A metric that always reads a suspiciously round number (0%, 100%) is
  usually broken, not informative.** Three prior attempts tuned the same
  idle-hook approach without questioning whether idle-hook timing was the
  right technique at all for a core that never voluntarily blocks except
  via a delay added *for the metric's own sake*.
- **A code comment stating an assumption ("860 SPS gives ~1.16ms/sample")
  is not the same as code that enforces it.** The library's default (128
  SPS) silently won because nothing called `setDataRate()`. Assumptions
  about hardware config belong in an assertion or an explicit call, not
  just a comment.
- **The fastest fix for a blocking-call problem (crank up the hardware
  speed) can trade away accuracy you didn't know you were relying on.**
  Sample rate and filter bandwidth are coupled on a sigma-delta ADC; "make
  it faster" and "keep it accurate" are two different knobs, and only one
  of them (making the read non-blocking) actually solves the scheduling
  problem without a tradeoff.
- **Verify safety-relevant sensor changes against a real reference, not
  just "does it still report a number."** The 860 SPS fix passed every
  check available at the time (builds, boots cleanly, current values look
  plausible, no invalid/zero reads) and still had a 67% error on one
  channel. A clamp meter on the actual wire caught what none of the
  software-side checks could.
- **Wall-clock busy-time accounting can conflate "genuinely executing" with
  "blocked in a busy-poll."** The fix here happened to reveal the real bug
  because the blocking ADC poll *is* wall-clock CPU-bound (a tight
  `while(!conversionComplete());` loop), but the same technique would
  overcount if a task instead blocked on something that lets other
  same/higher-priority work run in the gap (e.g. AsyncTCP, priority 10,
  unpinned). A `loopItersPerSec` counter alongside the load percentage is
  what made it possible to tell "really busy" apart from "frequently
  interrupted" without more invasive instrumentation.
- **Fixing an unrelated cosmetic dashboard bug can surface a much more
  serious latent one.** The internal-temp offset question that started this
  session had nothing to do with the current-sensor stall, but following
  the CPU-load thread all the way through was what found it.
- **"Within plausible tolerance" from a single comparison is not
  verification.** The +11% fan reading after fix #2 was accepted as good
  enough — but it compared a fresh device reading against a *stale* clamp
  reading taken earlier, at a different (and by then already-changed)
  load. Three more sessions, timed as close to simultaneously as possible,
  showed both channels were actually off by ~20-25%, consistently, in the
  same direction. A single data point can't distinguish "correct" from
  "coincidentally close."
- **Find a control variable to separate real signal from measurement
  error.** Compressor current legitimately varies with ambient/heat load,
  which made compressor-channel deltas across sessions ambiguous on their
  own. Fan current doesn't vary with heat load the same way, so a fan
  channel that showed the *same* error magnitude across independent
  sessions — while its own raw reading also stayed roughly flat — was the
  signal that separated "real, fixable calibration gap" from "the load
  changed" or "one bad reading."
- **A form with UI for a field but no backend wiring fails silently, not
  loudly.** The current-monitoring config fields looked fully implemented
  (dropdowns, burden-resistor inputs, overcurrent thresholds, a live tag)
  and had presumably looked that way for a while — nothing in the UI
  indicated the save was a no-op. Worth periodically checking that every
  input on a settings form actually round-trips, not just that it renders.

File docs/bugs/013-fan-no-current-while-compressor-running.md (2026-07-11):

# BUG-013: FAN not moving air while compressor is energized (no airflow safety)

**Date**: 2026-07-11
**Severity**: Critical
**Status**: Fixed
**Affected versions**: v1.0 through v1.3-rc?
**Fixed in**: `f9f836a`

## Symptom

Compressor (CNT) energized while the FAN output was OFF, or FAN output ON
but the fan motor drawing no current (seized bearing, blown capacitor,
disconnected wire, tripped internal thermal). Compressor continued to run
against a static coil, driving head pressure and discharge temperature
rapidly upward with no protective shutdown from the controller. Only the
compressor's own internal overtemp and the LPS switch would (eventually)
save the unit.

Additionally, the `FAN_CURRENT` reading occasionally reported `0.00A`
during normal fan operation, producing false-positive log noise and
undermining any downstream safety logic that trusted the reading.

## Impact

- **Compressor damage risk** — running a heat pump with no condenser (or
  evaporator, in HEAT) airflow is one of the fastest ways to destroy a
  compressor. Head pressure climbs, LPS may not trip on the low side, and
  by the time compressor overtemp (240°F) hits, permanent damage is likely
- Silent failure — no fault, no MQTT event, dashboard shows CNT green
- Current-sensor accuracy problem made a data-driven watchdog untrustworthy
  until the sensor itself was fixed
- Affected every operating mode that runs CNT: HEAT, COOL, and any
  post-defrost restart

## Root Cause

Two independent problems combined into one safety gap:

### 1. Missing CNT⇒FAN invariant and no airflow watchdog

`GoodmanHP` treated FAN and CNT as independently-driven outputs. The
state machine set them correctly on entry to each state, but several
transition paths could leave CNT ON while FAN drifted OFF:

- HEAT→COOL cancel path (mode-change race) toggled RV and re-evaluated
  outputs without re-asserting FAN
- CNT (re)activation after short-cycle timeout only wrote CNT, trusting
  a stale FAN value
- Periodic `updateState()` output validation checked each output against
  the state table independently, so a FAN=OFF glitch would be "validated"
  as correct if the table happened to allow it at that instant

There was **no** check whatsoever that the fan motor was actually drawing
current when the controller believed it was running. A blown run
capacitor, seized bearing, tripped thermal, or broken wire produced zero
protective response.

### 2. `CurrentSensor::readRMS()` false-zero reads

The old RMS implementation had three subtle bugs that combined to emit
`0.00A` reads on a healthy fan channel:

- **Only 20 samples over ~23 ms.** At 60 Hz that's ~1.4 line cycles, and
  I2C jitter from WiFi / AsyncTCP / SD log-flush interrupts routinely
  bunched samples near a zero crossing, producing a near-zero sum-of-squares
- **`sqrt(mean(v²))` with no DC-mean subtraction.** The differential input
  is not perfectly centered on 0 V (ADS1115 offset drift, non-symmetric
  sample windows), so the "RMS" formula was actually computing
  `sqrt(AC² + DC²)` — occasionally producing a spurious near-zero result
  when signed samples happened to cancel
- **All-zero I2C read treated as `0.00A`.** When the ADS1115 NACKed under
  bus contention every sample came back as `0`, and the sensor cheerfully
  published `0.00 A` instead of marking the reading invalid

Any watchdog built on top of this sensor would fire false alarms.

## Fix

### CurrentSensor (`src/CurrentSensor.cpp`)

- Increased sample count from 20 → **60** (~70 ms, ~4 full 60 Hz cycles)
  to average out I2C-induced sample bunching
- Proper AC-RMS: subtract DC mean before squaring
  (`variance = mean(v²) − mean(v)²`, then `sqrt(variance)`)
- Reject all-zero reads as **invalid** (`_valid = false`) with a
  `CURRENT` warn log — never publish a fake `0.00 A`
- Guard against FP round-off producing negative variance

### GoodmanHP airflow invariant

- Every code path that turns CNT ON now also asserts FAN ON in the same
  block — HEAT→COOL cancel path, short-cycle re-activation,
  `updateState()` output validation
- New periodic `checkFanFault()` task inspects `FAN_CURRENT` whenever CNT
  is energized

### GoodmanHP FAN current watchdog (`checkFanFault`)

New protection with three tunable constants in `GoodmanHP.h`:

```cpp
static constexpr float FAN_MIN_RUNNING_AMPS = 0.3f;              // Below this = FAN not running
static const uint32_t FAN_NO_CURRENT_TIMEOUT_MS = 20UL * 1000;   // 20s to see FAN current
static const uint32_t FAN_FAULT_ERROR_MS       = 3UL * 60 * 1000; // 3 min ERROR lockout
static const uint8_t  FAN_LOW_CONSECUTIVE_REQUIRED = 3;          // Debounce
```

Behavior:

- Only armed when CNT is ON (compressor actually needs airflow)
- Requires **3 consecutive** low reads (~3 s at 1 Hz current-sensor
  polling) before starting the 20 s timer — filters single-sample I2C
  glitches
- If FAN current stays below `FAN_MIN_RUNNING_AMPS` for
  `FAN_NO_CURRENT_TIMEOUT_MS` while CNT is on: shut down CNT, latch
  `ERROR` state for `FAN_FAULT_ERROR_MS` (3 min lockout)
- Blocks CNT re-activation while lockout is active
- Auto-recovers after 3 min; watchdog re-arms on the next CNT activation

### Grep-friendly logging

All watchdog events emit `FAN_FAULT:` and `FAN_SAFETY:` tagged lines
including `Y=`, `O=`, `state=`, `amps=`, `pin=`, and `elapsed=` so a
post-mortem grep against the SD log tells the full story of a shutdown.

## Affected Code

- `include/GoodmanHP.h`: watchdog constants, new state fields
  (`_fanFault`, `_fanFaultStartTick`, `_fanNoCurrentStartTick`,
  `_fanLowConsecutive`), `checkFanFault()` declaration, public
  accessors (`isFanFaultActive()`, `getFanFaultRemainingMs()`,
  `clearFanFault()`)
- `src/GoodmanHP.cpp`: `checkFanFault()` implementation, CNT⇒FAN
  invariant asserted at every CNT-on site, task scheduling, richer log
  tags
- `src/CurrentSensor.cpp`: 60-sample RMS with DC-mean subtraction,
  all-zero-read invalidation

## Detection

Field report of `0.00 A` on `FAN_CURRENT` while the fan was audibly
running led to inspecting `CurrentSensor::readRMS()`. Code review of
`GoodmanHP` transitions then revealed CNT-on paths that did not assert
FAN, and the total absence of any current-based airflow check. Bench
verification: forcing FAN OFF via manual override with CNT commanded ON
now shuts CNT down within 20 s and latches ERROR for 3 min; disconnecting
the fan run wire reproduces the same shutdown with FAN output still
electrically ON.

## Lessons Learned

- **Commanding an output ON is not evidence that a load is running.**
  Any safety-critical output that drives a motor needs a current-based
  liveness check, not just a GPIO state
- **RMS is not `sqrt(mean(v²))`** unless you can prove the signal is
  DC-free. On a real ADC with real offset drift, always subtract the
  measured DC mean per sample window
- Sample **enough** line cycles to swamp scheduler jitter. On an ESP32
  with WiFi + AsyncTCP + SD I/O sharing cores, 1–2 cycles is not enough
- **Invalid ≠ zero.** A sensor that can't get a good read must say
  "invalid" — publishing `0.00A` from an I2C NACK poisons every
  downstream safety check
- **Invariants belong at every write site, not just at state entry.**
  "CNT on ⇒ FAN on" has to be re-asserted anywhere CNT is written, or a
  future edit will silently break the invariant
- **Debounce safety watchdogs.** A single 0-A sample is a glitch;
  three in a row is a signal. Require consecutive confirmations before
  arming a timer that will shut down the compressor

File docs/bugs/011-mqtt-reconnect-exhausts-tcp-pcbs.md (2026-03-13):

# BUG-011: MQTT reconnect loop exhausts lwIP TCP PCBs

**Date**: 2026-03-10
**Severity**: High
**Status**: Fixed
**Affected versions**: v1.0 through v1.2-rc16
**Fixed in**: `dceef77`

## Symptom

Device becomes completely unresponsive after running for multiple days with
the MQTT broker unreachable. No WDT/panic reset — device appears frozen.
HTTP, HTTPS, MQTT, and weather fetch all stop working simultaneously.
Requires physical power cycle to recover. Ping may also fail.

## Impact

- Total loss of network connectivity — HTTP server unreachable, no remote
  monitoring or control
- Heat pump control loop continues running (outputs/inputs work), but no
  remote visibility
- No crash dump or reset reason — appears as a silent hang
- Requires physical access to recover (power cycle)

## Root Cause

The MQTT reconnect task (`_tReconnect`) attempted a new connection every
10 seconds unconditionally. When the MQTT broker was unreachable, each
`_client.connect()` call created a TCP socket that went through
SYN_SENT → TIME_WAIT states in the lwIP stack.

Over extended periods (observed: 7 days), ~60,000+ TCP connection attempts
accumulated. The lwIP TCP PCB (Protocol Control Block) pool is finite —
each failed connection leaves a PCB in TIME_WAIT for up to 120 seconds.
With connections every 10 seconds, the PCB pool eventually exhausted:

- No new TCP connections possible (MQTT, HTTP server, weather fetch)
- HTTP server cannot accept incoming connections — device unreachable
- ICMP/ping may also fail once lwIP is completely jammed
- Main loop continues running (WDT happy) — no crash, just network-dead

Log pattern observed: continuous "Connecting to MQTT..." / "Disconnected
from MQTT (reason: 0)" every ~10 seconds for 7 days straight with no
successful connection.

## Fix

Added exponential backoff to the MQTT reconnect task. Interval doubles
on each failed attempt, capped at 5 minutes. Resets to 10 seconds on
successful connection:

```cpp
// Exponential backoff: 10s → 20s → 40s → 80s → 160s → 300s (cap)
_consecutiveFailures++;
uint32_t nextInterval = _reconnectIntervalSec * 2;
if (nextInterval > RECONNECT_MAX_SEC)
    nextInterval = RECONNECT_MAX_SEC;
_reconnectIntervalSec = nextInterval;
_tReconnect->setInterval(_reconnectIntervalSec * TASK_SECOND);
```

On successful connect (`onConnect`), backoff resets:

```cpp
_consecutiveFailures = 0;
_reconnectIntervalSec = RECONNECT_MIN_SEC;
_tReconnect->setInterval(RECONNECT_MIN_SEC * TASK_SECOND);
```

Reduces TCP churn from ~60,000 attempts/week to ~2,000 (30x reduction).

## Affected Code

- `include/MQTTHandler.h`: Added backoff member variables and constants
- `src/MQTTHandler.cpp`: Backoff logic in reconnect task, reset in
  `onConnect()`

## Detection

Device at 192.168.1.138 became unreachable after 7 days (2026-03-03 to
2026-03-10). SD card log showed continuous MQTT connect/disconnect loop
at 10-second intervals for the entire session. Last log entry was a normal
"Connecting to MQTT..." followed by silence — then fresh POWERON boot
after manual power cycle.

## Lessons Learned

- Unbounded retry loops on network operations will eventually exhaust
  lwIP resources on ESP32 — always use backoff
- The failure mode is silent (no crash/panic/WDT) because the main loop
  continues running — only networking dies
- AsyncMqttClient's TCP connections consume lwIP PCBs even on failure —
  high-frequency retries are dangerous

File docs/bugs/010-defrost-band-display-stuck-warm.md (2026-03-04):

# BUG-010: Defrost band display stuck on Warm in non-HEAT states

**Date**: 2026-03-04
**Severity**: Low (cosmetic)
**Status**: Fixed
**Affected versions**: v1.2-rc15
**Fixed in**: `fd030e4` (v1.2-rc16)

## Symptom

Dashboard and `/state` JSON report `defrostBand: "Warm"` with 90-minute
threshold while ambient temperature is 30°F — should show Mid band with
60-minute threshold. The band snaps to the correct value when the system
enters HEAT mode.

## Impact

- Cosmetic only — dashboard and OLED show wrong band and threshold in
  OFF and COOL states
- No effect on defrost behavior — `selectDefrostBand()` is called again
  when defrost actually triggers, always in HEAT mode
- Confusing to operators monitoring the system during idle periods

## Root Cause

Regression introduced by the BUG-009 fix (`932b969`). The `State::HEAT`
guard added to prevent defrost triggering in OFF state was placed **above**
the `selectDefrostBand()` call:

```cpp
// BUG-009 fix — but band update was below the guard
if (_state != State::HEAT) return;

// This only runs in HEAT now
_activeDefrostBand = selectDefrostBand();
```

`_activeDefrostBand` is initialized to `DefrostBandName::WARM` in the
constructor (line 22). With the guard in place, it was never updated
outside of HEAT mode, so the dashboard always showed Warm/90min when
the system was OFF or in COOL.

Prior to BUG-009, `selectDefrostBand()` ran unconditionally every 500ms
in `checkDefrostNeeded()`, keeping the display current in all states.

## Fix

Moved `selectDefrostBand()` above the HEAT guard so the band updates
in all states while the runtime threshold check remains gated:

```cpp
// Always update active band for dashboard display
_activeDefrostBand = selectDefrostBand();

// Only trigger new defrost while in HEAT state
if (_state != State::HEAT) return;
```

`selectDefrostBand()` is read-only (reads ambient sensor, returns enum)
and safe to call in any state.

## Affected Code

- `src/GoodmanHP.cpp`: Reordered `selectDefrostBand()` and HEAT guard
  in `checkDefrostNeeded()`

## Detection

Noticed via dashboard — ambient was 30°F but band displayed as Warm
instead of Mid immediately after deploying v1.2-rc15 (BUG-009 fix).

## Lessons Learned

- When adding early-return guards to a function, audit what else the
  function updates that may be needed regardless of the guard condition.
  `_activeDefrostBand` was a display-facing side effect that needed to
  survive the guard.

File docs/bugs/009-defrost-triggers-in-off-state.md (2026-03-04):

# BUG-009: Defrost triggers in OFF state when runtime threshold reached

**Date**: 2026-03-04
**Severity**: Low (self-correcting)
**Status**: Fixed
**Affected versions**: v1.0 through v1.2-rc9
**Fixed in**: `932b969` (v1.2-rc15)

## Symptom

Log at 21:08:38:
```
[INFO ] [HP] Heat runtime 79 min >= 60 min threshold (band=Mid), starting defrost
[INFO ] [HP] Starting defrost transition (band=Mid, minRT=90 s, exit=55.0F, 30 s RV short cycle)
[WARN ] [HP] Y inactive during defrost/exit sequence, all outputs OFF
```

Defrost initiated while system was in OFF state (Y dropped 32 minutes earlier
at 20:36). `startSoftwareDefrost()` set transition flags, then the Y-inactive
safety abort in `checkDefrostNeeded()` immediately cancelled the transition on
the next update cycle. `_softwareDefrost` stayed latched, causing defrost to
resume from Phase 1 when Y reactivated 5 minutes later at 21:13.

## Impact

- No equipment damage — the Y-inactive safety gate (BUG-001 fix) caught the
  invalid state within 500ms and shut everything down
- Defrost ultimately completed successfully at 21:13–21:17 via the
  `_softwareDefrost` resume path
- Unnecessary WARN log entry and one wasted start/abort cycle
- Outputs were already OFF during the abort, so no relay switching occurred
  (CNT, FAN, W all logged `State: 0 Requested State: 0`)

## Root Cause

`checkDefrostNeeded()` in `GoodmanHP.cpp` had **no state guard** before the
runtime threshold check at line 1870. The function was called unconditionally
from `update()` every 500ms regardless of system state.

The execution flow in `update()`:
```
accumulateHeatRuntime()   // line 256 — correctly guards on State::HEAT
updateState()             // line 257 — Y inactive, stays OFF
checkDefrostNeeded()      // line 258 — NO state guard, runtime check fires
```

`accumulateHeatRuntime()` correctly only accumulates when
`_state == State::HEAT && cnt->isOn()`, so runtime wasn't growing during OFF.
However, the accumulated runtime from previous HEAT cycles (79 min across
~6 short thermostat cycles) persisted because:
1. System never entered COOL (which resets runtime)
2. DFT stayed active (so the DFT-off 30s debounce reset never triggered)

When `checkDefrostNeeded()` reached the runtime threshold check, it saw
79 min >= 60 min (Mid band) and called `startSoftwareDefrost()`. This set
`_defrostTransition = true` and `_softwareDefrost = true`. On the next update
cycle (same log second), the Y-inactive check at line 1740 saw the transition
flags with Y inactive and aborted.

```cpp
// Line 1740 — Y-inactive safety abort
if (!yActive && (_defrostExiting || _defrostTransition || _defrostCntPending)) {
    // ... turn off all outputs, clear transition flags
    // _softwareDefrost stays set for resume
    return;
}

// Line 1870 — runtime threshold check (NO state guard)
_activeDefrostBand = selectDefrostBand();
const DefrostBand& band = _defrostBands[(int)_activeDefrostBand];
if (_heatRuntimeMs >= band.runtimeThresholdMs) {
    startSoftwareDefrost();  // BUG: fires in OFF state
}
```

## Fix

Added state guard before the runtime threshold check in `checkDefrostNeeded()`:

```cpp
// Only trigger new defrost while in HEAT state (Y active, compressor running)
if (_state != State::HEAT) return;

// Select band from current ambient temperature
_activeDefrostBand = selectDefrostBand();
const DefrostBand& band = _defrostBands[(int)_activeDefrostBand];
```

The guard is placed after all ongoing defrost/exit transition handling (phases,
Y-abort) so those continue to function regardless of state. Only the new-defrost
trigger is gated.

State::HEAT is sufficient because:
- HEAT requires Y active (that's how we enter HEAT)
- OFF transitions bypass state validation (high priority), so Y drop →
  immediate OFF before next `checkDefrostNeeded()` call
- `updateState()` runs before `checkDefrostNeeded()` in `update()`, so state
  is always current

## Affected Code

- `src/GoodmanHP.cpp`: Added `if (_state != State::HEAT) return;` before
  band selection and runtime threshold check in `checkDefrostNeeded()`

## Timeline (from logs)

```
20:36:26  Y input deactivated, CNT turned off
20:36:26  State: HEAT -> OFF
          ... 32 minutes in OFF state, runtime frozen at 79 min ...
21:08:38  Heat runtime 79 min >= 60 min threshold (band=Mid), starting defrost    ← BUG
21:08:38  Starting defrost transition (band=Mid, minRT=90s, exit=55.0F)
21:08:38  CNT State: 0 Req: 0  (already off — no relay switch)
21:08:38  FAN State: 0 Req: 0  (already off — no relay switch)
21:08:38  Y inactive during defrost/exit sequence, all outputs OFF                ← abort
          ... _softwareDefrost stays latched ...
21:13:23  Y change detected (active), validating in 2000ms
21:13:26  State: OFF -> DEFROST                                                   ← resume
21:13:26  Defrost resuming, restarting transition from Phase 1
21:13:56  Phase 1 complete, engaging RV+W
21:14:26  Phase 2 complete, engaging CNT — defrost fully active
21:16:56  Defrost complete: condenser 60.3F >= 55.0F (band=Mid)
21:16:56  Defrost complete, starting exit transition
21:17:27  Exit Phase 1 complete, RV off
21:17:57  Exit Phase 2 complete, CNT+FAN on — back in HEAT mode
21:18:28  Config saved (defrost=0, runtime=0 ms)
```

## Detection

Discovered via log review — the `[WARN] Y inactive during defrost/exit
sequence` message flagged an unexpected abort. Cross-referencing timestamps
confirmed the system was in OFF state when defrost triggered.

## Lessons Learned

- `checkDefrostNeeded()` handles both ongoing transitions and new triggers
  in the same function. Guards for new triggers (state-dependent) must be
  separate from guards for ongoing transitions (state-independent).
- The defense-in-depth from BUG-001 (Y-inactive safety gate) prevented this
  from becoming a real issue — the abort path worked exactly as designed.
- Heat runtime persisting across thermostat cycles is correct behavior, but
  the threshold check must only fire when the system is actually running.

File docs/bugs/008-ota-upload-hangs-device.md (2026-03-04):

# BUG-008: OTA upload hangs device due to concurrent SD access

**Date**: 2026-03-03
**Severity**: High
**Status**: Fixed
**Affected versions**: v1.0 through v1.2-rc8
**Fixed in**: `a75ab7b`

## Symptom

Device becomes completely unresponsive during OTA firmware upload via
`POST /update`. No WDT/panic reset — just frozen. Requires physical power
cycle to recover.

## Impact

- OTA firmware updates unreliable — device hangs mid-upload
- No crash dump or WDT reset, making diagnosis difficult
- Requires physical access to recover (power cycle)

## Root Cause

The HTTPS `httpd` task runs on a separate FreeRTOS task from the Arduino
`loop()`. The OTA handler performed `httpd_req_recv()` + `SD.write()` in a
tight loop with a 1024-byte buffer (~1500 iterations for a 1.5MB firmware).

Meanwhile, the main loop continued running tasks that access SD:
- `Logger` — log file writes
- `tSaveRuntime` — config runtime persistence (every 5 min)
- `tLogTempsCSV` — temperature CSV logging (every 30s)

The Arduino SD library is **not thread-safe**. Concurrent SPI bus access from
multiple FreeRTOS tasks corrupts the SPI bus state, causing a deadlock where
both tasks wait indefinitely on the SPI peripheral.

## Fix

Buffer the entire firmware in PSRAM before writing to SD:

```cpp
// Allocate full firmware buffer in PSRAM
uint8_t* fwBuf = (uint8_t*)heap_caps_malloc(totalSize, MALLOC_CAP_SPIRAM);

// Receive entire firmware into PSRAM buffer
while (remaining > 0) {
    int ret = httpd_req_recv(req, (char*)(fwBuf + offset), remaining);
    offset += ret;
    remaining -= ret;
}

// Single SD write after receive completes
File f = SD.open("/firmware.new", FILE_WRITE);
f.write(fwBuf, totalSize);
f.close();
heap_caps_free(fwBuf);
```

Also bumped HTTPS httpd task stack from 10KB to 16KB.

## Affected Code

- `src/HttpsServer.cpp`: OTA upload handler — PSRAM buffering, stack size

## Lessons Learned

- Arduino SD is NOT thread-safe — any code on non-Arduino FreeRTOS tasks
  (HTTPS httpd, AsyncTCP) must minimize SD access duration
- Use PSRAM buffering for large transfers to avoid SPI bus corruption with
  main loop SD operations
- SPI bus deadlocks don't trigger WDT because the tasks are technically
  still running (blocked on SPI, not in an infinite loop)

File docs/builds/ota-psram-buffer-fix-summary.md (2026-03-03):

# OTA Upload PSRAM Buffer Fix

**Date:** 2026-03-03

## Problem

OTA firmware uploads (`POST /update`) consistently hung the device, requiring a power cycle to recover. The device would become completely unreachable (no ping, no HTTP) with no WDT/panic reset recorded (crash boots stayed at 0). Reproducible on both HTTP (AsyncWebServer) and HTTPS (ESP-IDF httpd) paths.

## Root Cause

**Concurrent SD card access from multiple FreeRTOS tasks without thread safety.**

The OTA upload handlers ran on separate FreeRTOS tasks from the Arduino loop:
- HTTPS: ESP-IDF httpd task
- HTTP: AsyncTCP task

Both handlers used a tight `recv() + SD.write()` loop with a 1024-byte buffer — ~1500 iterations for a 1.5MB firmware, taking 10-30 seconds. During that window, the Arduino loop's scheduled tasks continued accessing SD:
- `Logger::writeToSdCard()` on every log entry
- `tSaveRuntime` every 5 minutes
- `tLogTempsCSV` every 30 seconds

The Arduino SD library uses SPI and is **not thread-safe**. When two FreeRTOS tasks on different cores call `SD.open()`/`SD.write()` simultaneously, the SPI bus state gets corrupted, causing one or both tasks to spin-wait indefinitely on an SPI transfer that will never complete — a deadlock, not a crash.

## Fix

Buffer the entire firmware in PSRAM during the network receive phase, then write to SD in a single operation after all data is received. This eliminates the long concurrent SD access window (from ~30 seconds down to a fraction of a second).

### HTTPS handler (`HttpsServer.cpp`)

**Before:** Blocking `while` loop doing `httpd_req_recv()` + `fw.write()` with 1024-byte buffer
```cpp
char buf[1024];
while (remaining > 0) {
    int ret = httpd_req_recv(req, buf, toRead);
    fw.write((uint8_t*)buf, ret);  // SD write on every iteration
    remaining -= ret;
}
```

**After:** Receive into PSRAM, then single SD write
```cpp
uint8_t* fwBuf = (uint8_t*)heap_caps_malloc(total, MALLOC_CAP_SPIRAM);
while (received < total) {
    int ret = httpd_req_recv(req, (char*)(fwBuf + received), total - received);
    received += ret;  // No SD access during recv
}
fw.write(fwBuf, total);  // Single SD write after all data received
```

Also increased httpd task stack size from 10KB (default) to 16KB for TLS + SD operation headroom.

### HTTP handler (`WebHandler.cpp`)

**Before:** AsyncWebServer body callback doing `SD.write()` on every chunk
```cpp
// Body handler called per chunk
if (_otaFile) {
    _otaFile.write(data, len);  // SD write on every chunk
}
```

**After:** Buffer chunks in PSRAM, single SD write on last chunk
```cpp
// Body handler called per chunk
if (_otaBuffer && index + len <= _otaTotal) {
    memcpy(_otaBuffer + index, data, len);  // PSRAM only, no SD
}
if (index + len == total && _otaBuffer) {
    File fw = SD.open("/firmware.new", FILE_WRITE);
    fw.write(_otaBuffer, _otaTotal);  // Single SD write at end
}
```

## Files Modified (3 files)

| File | Changes |
|---|---|
| `src/HttpsServer.cpp` | Rewrote `updatePostHandler()`: PSRAM buffer for recv, single SD write, 2MB size limit. Increased `cfg.httpd.stack_size` to 16384 |
| `src/WebHandler.cpp` | Rewrote `/update` body handler: PSRAM buffer via `heap_caps_malloc`, `memcpy` per chunk, single SD write on final chunk |
| `include/WebHandler.h` | Replaced `File _otaFile` with `uint8_t* _otaBuffer` and `size_t _otaTotal` |

## Verification

| Test | Result |
|---|---|
| OTA to test board (.136) via HTTPS | OK in 5.8s |
| OTA to production (.138) via HTTPS | OK in 5.5s |
| Apply + reboot on production | Clean boot, new firmware running |
| Test board still responsive after OTA | Confirmed |

Previously both devices hung on every OTA attempt.

## Key Takeaway

The Arduino SD library (SPI-based) is not thread-safe. Any code running on a non-Arduino FreeRTOS task (HTTPS httpd, AsyncTCP, etc.) must minimize SD access duration to avoid SPI bus corruption with the main loop's SD operations. PSRAM buffering is the preferred pattern for large transfers.

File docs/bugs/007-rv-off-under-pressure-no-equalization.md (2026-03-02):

# BUG-007: RV relay turned off under pressure without equalization delay

**Date**: 2026-03-02
**Severity**: Medium (equipment protection)
**Status**: Fixed
**Affected versions**: v1.0 through v1.2-rc8
**Fixed in**: v1.2-rc9

## Symptom

When the system transitions from COOL → OFF (or any state where RV and CNT
are both active to OFF), the reversing valve solenoid is de-energized
immediately while the refrigerant system is still under compressor discharge
pressure. The valve attempts to switch position against high-pressure
differential, causing mechanical stress and potential valve damage.

## Impact

- Reversing valve switches under full system pressure on every COOL → OFF
  transition, every Y-drop during defrost Phase 3, every LOW_TEMP activation
  from COOL mode, and several other abort paths
- Repeated pressure-switching can shorten reversing valve lifespan and cause
  the valve to fail to seat properly
- No immediate equipment failure, but cumulative mechanical wear on the
  most expensive single component in the heat pump system

## Root Cause

The existing code had proper pressure equalization sequencing for **planned
mode transitions** (COOL→HEAT, HEAT→COOL, defrost exit) — these all use
multi-phase sequences that wait `_rvShortCycleMs` (default 30s) after CNT
turns off before switching RV.

However, **9 code paths** turned RV off immediately with no delay:

1. `updateState()` — direct transition to OFF or HEAT when no sequenced
   transition applies
2. `checkAmbientTemp()` — LOW_TEMP protection activation
3. Y drop during active defrost (Phase 3, CNT running)
4. Y drop during defrost exit
5. COOL transition abort (Y or O drops mid-transition)
6. HEAT transition abort (Y drops mid-transition)
7. RV fail detection (shuts down defrost)
8. Y inactive safety abort in `checkDefrostNeeded()`
9. `stopSoftwareDefrost()` with Y inactive

All of these called `rv->turnOff()` directly, bypassing pressure
equalization. The common pattern was CNT being turned off in the same
function call (or moments before), followed immediately by RV off — giving
zero time for the refrigerant pressures to equalize.

## Fix

Added `safeRvOff()` helper method that checks CNT timing before switching RV:

```cpp
void GoodmanHP::safeRvOff() {
    OutPin* rv = getOutput("RV");
    if (rv == nullptr || !rv->isOn()) return;

    OutPin* cnt = getOutput("CNT");
    uint32_t cntOffElapsed = millis() - cnt->getOffTick();

    if (!cnt->isOn() && cntOffElapsed >= _rvShortCycleMs) {
        rv->turnOff();  // Pressure equalized — safe
    } else {
        _rvHoldActive = true;  // Hold RV on until equalized
    }
}
```

`checkRvHold()` runs every 500ms in `update()` and turns RV off once CNT
has been off for `_rvShortCycleMs`. The hold auto-cancels if a sequenced
transition takes over RV management (cool/heat transition, defrost phases).

All 9 immediate-off call sites replaced with `safeRvOff()`. Two existing
call sites that were already inside sequenced transitions (HEAT transition
Phase 1→2, defrost exit Phase 1→2) kept as direct `rv->turnOff()` since
they already waited the full equalization period.

Additional safety:
- CNT activation blocked during `_rvHoldActive` (prevents compressor running
  with RV in wrong position)
- Output state validator skips RV enforcement during hold (`expRV = -1`)
- Hold cancelled if any transition flag becomes active

## Affected Code

- `src/GoodmanHP.cpp`: Added `safeRvOff()`, `checkRvHold()`, replaced 9
  `rv->turnOff()` calls
- `include/GoodmanHP.h`: Added `_rvHoldActive` member, method declarations,
  public accessors
- `src/WebHandler.cpp`: Added `rvHold`/`rvHoldRemainSec` to `/state` JSON
  and MQTT state
- `src/HttpsServer.cpp`: Mirrored `rvHold`/`rvHoldRemainSec` in HTTPS
  `/state` handler
- `data/www/dashboard.html`: Added "Hold" pill with countdown on RV indicator
- `data/www/pins.html`: Added "RV Hold (Pressure EQ)" flag
- `src/DisplayManager.cpp`: Added "RV Hold" to OLED protections page

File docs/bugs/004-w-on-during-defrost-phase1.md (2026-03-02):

# BUG-004: W relay turned ON during defrost Phase 1

**Date**: 2026-03-01
**Severity**: Medium
**Status**: Fixed
**Affected versions**: v1.1 through v1.2-rc6
**Fixed in**: v1.2-rc7

## Symptom

State validator logged:
```
[ERROR] [HP] STATE CHECK: W on in DEFROST Ph1 — forcing OFF
```

W (auxiliary heat) relay was momentarily energized during defrost Phase 1
(pressure equalization), when all outputs should be OFF.

## Impact

- W relay turned ON for up to 10 seconds during Phase 1 before the state
  validator caught and corrected it
- No equipment damage — the state validator auto-corrected the output
- Phase 1 is only 30 seconds, so W was on for a fraction of that window
- Functionally low risk: W energizes the backup heat strips, which is harmless
  during the brief pressure equalization period

## Root Cause

**Race condition in `updateState()` block ordering** (`GoodmanHP.cpp`).

When entering DEFROST from another state (e.g., OFF or HEAT), the W control
block ran BEFORE the Phase 1 restart block:

```
// Block A (ran first): W control
if (newState == DEFROST && !_defrostTransition) {  // _defrostTransition still false!
    w->turnOn();  // BUG: W turned on prematurely
}

// Block B (ran second): Phase 1 setup
if (newState == DEFROST && _softwareDefrost && oldState != DEFROST) {
    _defrostTransition = true;  // Now it's true, but too late
}
```

The `!_defrostTransition` guard on the W control was intended to prevent W
from turning on during Phase 1. However, `_defrostTransition` was only set
to `true` by the Phase 1 restart block, which executed AFTER the W control
block. At the time W was evaluated, `_defrostTransition` was still `false`.

## Fix

Moved the Phase 1 restart block BEFORE the W control block in `updateState()`.
Now `_defrostTransition` is `true` when W is evaluated, and the
`!_defrostTransition` guard correctly prevents W from turning on.

W is properly turned on later by `checkDefrostNeeded()` when Phase 1 completes
and Phase 2 begins (line 1548: RV + W on).

## Affected Code

- `src/GoodmanHP.cpp`: `updateState()` — reordered blocks at ~line 716

## Detection

Caught by the table-driven output state validator (`validateOutputStates()`),
which runs every 10 seconds and checks all outputs against expected values for
the current state and transition phase. The validator auto-corrected W to OFF
and logged the ERROR.

## Timeline (from logs)

```
18:52:11  State check OK: OFF [FAN=OFF CNT=OFF RV=OFF W=OFF]
18:52:41  STATE CHECK: W on in DEFROST Ph1 — forcing OFF     ← BUG
18:53:11  State check OK: DEFROST [FAN=OFF CNT=OFF RV=ON W=ON]  ← Phase 2 (correct)
18:53:41  State check OK: DEFROST [FAN=OFF CNT=ON RV=ON W=ON]   ← Phase 3 (correct)
18:56:11  State check OK: HEAT [FAN=OFF CNT=OFF RV=OFF W=OFF]   ← Exit transition
18:56:41  State check OK: HEAT [FAN=ON CNT=ON RV=OFF W=OFF]     ← Normal HEAT
```

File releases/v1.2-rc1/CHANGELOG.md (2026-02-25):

# v1.2-rc1 — Release Candidate 1

**Date:** 2026-02-25
**Board:** Freenove ESP32-S3 WROOM N8R8 (8MB Flash / 8MB PSRAM)
**Build:** PlatformIO espressif32 6.12.0, Arduino ESP32 3.20017

## New Features

- **HEAT↔COOL mode transitions** — 3-phase sequenced reversing valve switching for both HEAT→COOL and COOL→HEAT, with pressure equalization and short cycle protection
- **State validation delay** — Configurable hold time (default 30s) after state changes prevents rapid cycling; HIGH priority states (OFF, ERROR) bypass
- **Table-driven output validation** — `validateOutputStates()` verifies all outputs match expected state every 10s, covers all transition phases, auto-corrects mismatches
- **Input pin polling** — Replaced ISR-based input detection with polling-based validation (default 2s delay), more reliable on ESP32-S3
- **DFT debounce** — 30-second sustained off required before heat runtime resets, prevents false resets from intermittent DFT contact
- **Defrost elapsed timer** — Dashboard pill shows running M:SS count-up during active defrost; orange "Defrost Pending" state when defrost flag set but Y dropped
- **WiFi AP mode** — Automatic fallback to AP mode after configurable WiFi disconnect timeout; random password, OLED display, auto-reconnect
- **Session-based authentication** — Login page with configurable session timeout, Basic Auth fallback for API/script compatibility
- **Boot watchdog + safe mode** — Auto-detects crash boot loops (3+ consecutive resets), enters safe mode; auto-reverts to backup firmware if available
- **OTA auto-revert** — Backs up running firmware before OTA update; reverts on crash boot loop if backup has different build date
- **Configurable system name + MQTT prefix** — Multi-unit support with customizable system name and MQTT topic prefix
- **SSD1306 OLED display** — 128x64 I2C display with 5 rotating pages (status, temps, I/O, system, protections)
- **MAX6675 SPI thermocouple** — Additional thermocouple source for LIQUID_TEMP with configurable pin mapping
- **Configurable FTP password** — Encrypted FTP credentials with timed enable (10/30/60 min auto-disable)
- **Configurable W/AUX in LOW_TEMP** — Independent enable checkboxes for W (auxiliary heat) and AUX relay in low ambient temp mode

## Bug Fixes

- Fix defrost pill showing red with stale elapsed time in OFF state when defrost is pending
- Fix `_defrostStartTick` not resetting on Y drop, causing stale elapsed time on resume
- Skip state validation timer during manual override
- Block manual override during startup lockout to prevent CNT activation
- Fix FTP password dangling pointer
- Fix HTTPS client IP logging
- Block USB JTAG and SD SPI bus pins from MAX6675 GPIO selection
- Fix AP test mode disconnecting WiFi before HTTP response completes
- Avoid bare I2C probe on MCP9600 to prevent chip crash and bus lockup
- Fix inflated CPU load by yielding every loop iteration
- Fix reboot button authentication on pins page

## Configuration Changes

New config keys (all backward-compatible with defaults):
- `heatpump.stateValidation.delayMs` — State hold time in ms (default 30000)
- `heatpump.inputDelay.ms` — Input validation delay in ms (default 2000)
- `heatpump.lowTemp.enableW` / `enableAux` — W/AUX enable in LOW_TEMP (default true)
- `wifi.apFallbackSeconds` — WiFi disconnect timeout before AP mode (default 600)
- `wifi.apPassword` — AP mode password (blank = auto-generate)
- `admin.password` — Admin password for web auth
- `ui.theme` — Light/dark theme preference

## Files

| File | Description |
|---|---|
| `firmware.bin` | ESP32-S3 firmware binary (OTA or USB flash) |
| `littlefs.bin` | LittleFS filesystem image (web UI pages) |

## Flash Instructions

**OTA (preferred):**
```bash
# Upload firmware
curl -k -u admin:PASSWORD https://DEVICE_IP/update --data-binary @firmware.bin

# Apply (backs up current firmware first)
curl -k -u admin:PASSWORD -X POST https://DEVICE_IP/apply

# Upload LittleFS (web pages)
curl -k -u admin:PASSWORD https://DEVICE_IP/upload/www -F "file=@littlefs.bin"
```

**USB:**
```bash
# Firmware
pio run -t upload -e freenove_esp32_s3_wroom

# LittleFS
pio run -t uploadfs -e freenove_esp32_s3_wroom
```

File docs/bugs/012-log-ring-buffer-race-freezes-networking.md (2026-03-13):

# BUG-012: Log ring buffer race condition freezes networking

**Date**: 2026-03-13
**Severity**: High
**Status**: Fixed
**Affected versions**: v1.0 through v1.2-rc16
**Fixed in**: `0ad4a02`

## Symptom

Accessing the log page causes it to show "loading..." and never return
results. Within seconds, all HTTP and HTTPS endpoints become unresponsive.
MQTT disconnects and weather HTTP fetches begin failing. Heat pump control
loop continues running normally — inputs, outputs, and SD card logging all
work. Requires physical power cycle to recover.

## Impact

- Total loss of network connectivity — identical symptom to BUG-011 but
  different root cause
- Triggered by user action (opening log page), not by time-based
  resource exhaustion
- Heat pump control continues but no remote monitoring or control
- No crash dump or reset reason — silent network death

## Root Cause

The `Logger` ring buffer (`std::vector<String>`, 500 entries) has no
thread synchronization. Three separate FreeRTOS tasks access it
concurrently:

1. **Main loop (core 1)**: `Logger::log()` calls `addToRingBuffer()` —
   overwrites `_ringBuffer[_ringBufferHead]` with a new String, advances
   `_ringBufferHead` and `_ringBufferCount`
2. **HTTPS httpd task (core 0)**: `logGetHandler()` calls
   `getRingBuffer()` (returns const reference to live vector), iterates
   all 500 entries character-by-character to build JSON
3. **AsyncTCP task (core 0)**: HTTP `/log` handler does the same via
   `AsyncWebServerRequest`

Additionally, `Logger::log()` uses a shared `_buffer[512]` member for
`snprintf()`. The `[AUTH] HTTPS session created` log message is emitted
from the httpd task, racing with main loop log calls on the same buffer.

The race condition:

1. HTTPS `logGetHandler` starts reading ring buffer entries on core 0
2. Main loop calls `Log.info()` → `addToRingBuffer()` on core 1
3. `addToRingBuffer()` overwrites `_ringBuffer[idx]` — the old String's
   internal buffer is freed
4. The httpd task reads the freed String — corrupted `length()` field
   causes infinite loop in the character-by-character JSON escaping loop
5. httpd task hangs → all HTTPS requests queue behind it (single-threaded)
6. Hung TCP connection cascades through lwIP, killing MQTT and HTTP

The log from 2026-03-13 confirms the sequence:
- `08:26:50` — HTTPS session created (user opened dashboard)
- `08:27:21` — MQTT disconnected (networking dying)
- `08:31:35` — Weather HTTP fetch failed (networking dead)
- `08:27–08:51` — HP control loop continued normally (Y/CNT/FAN events)
- Log page showed "loading..." and never returned

## Fix

Added a FreeRTOS mutex to the `Logger` class protecting all shared state:

1. **Mutex on `Logger::log()`** — serializes all writes to `_buffer` and
   ring buffer across tasks. Uses 100ms timeout — drops the log entry
   rather than deadlocking:

```cpp
void Logger::log(Level level, const char* tag, const char* format, va_list args) {
    if (xSemaphoreTake(_mutex, pdMS_TO_TICKS(100)) != pdTRUE) return;
    // ... format message, write to all outputs ...
    xSemaphoreGive(_mutex);
}
```

2. **`getLogJson(limit)`** — new method that snapshots ring buffer entries
   under the mutex, then builds JSON from the copy outside the mutex.
   Eliminates the race entirely — readers never touch the live buffer:

```cpp
String Logger::getLogJson(size_t limit) const {
    std::vector<String> entries;
    if (xSemaphoreTake(_mutex, pdMS_TO_TICKS(500)) == pdTRUE) {
        // Copy entries from ring buffer
        // ...
        xSemaphoreGive(_mutex);
    }
    // Build JSON from snapshot (outside mutex)
    // ...
}
```

3. Both `WebHandler.cpp` (`/log` HTTP) and `HttpsServer.cpp` (`/log`
   HTTPS) replaced with single call to `Log.getLogJson(limit)`.

## Affected Code

- `include/Logger.h`: Added `SemaphoreHandle_t _mutex`, `getLogJson()`
- `src/Logger.cpp`: Mutex init, `log()` protection, `getLogJson()` impl
- `src/WebHandler.cpp`: `/log` handler simplified to use `getLogJson()`
- `src/HttpsServer.cpp`: `logGetHandler` simplified to use `getLogJson()`

## Detection

User reported log page stuck on "loading..." at ~08:27 on 2026-03-13,
followed by complete HTTP/HTTPS unresponsiveness. SD card log showed
networking died (MQTT disconnect, weather fetch failures) while HP control
continued normally — classic symptom of a networking-layer hang with a
healthy main loop.

## Lessons Learned

- Any data structure accessed from multiple FreeRTOS tasks (httpd, AsyncTCP,
  Arduino loop) MUST have mutex protection — even read-only access is unsafe
  if another task is writing
- Returning `const&` to internal data structures invites unsynchronized
  access — prefer snapshot/copy methods for cross-task data
- String corruption from concurrent access doesn't always crash — it can
  cause infinite loops (corrupted length field) that silently freeze the
  accessing task
- The esp-idf httpd is single-threaded — one hung handler blocks all
  HTTPS requests, which cascades to kill lwIP networking
- Use bounded mutex timeouts (not `portMAX_DELAY`) to prevent deadlocks
  in logging — dropping a log entry is better than freezing

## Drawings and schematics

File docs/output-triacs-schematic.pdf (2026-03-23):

# KMOC3021S TLCOM

# KMOC3021S TLCOM

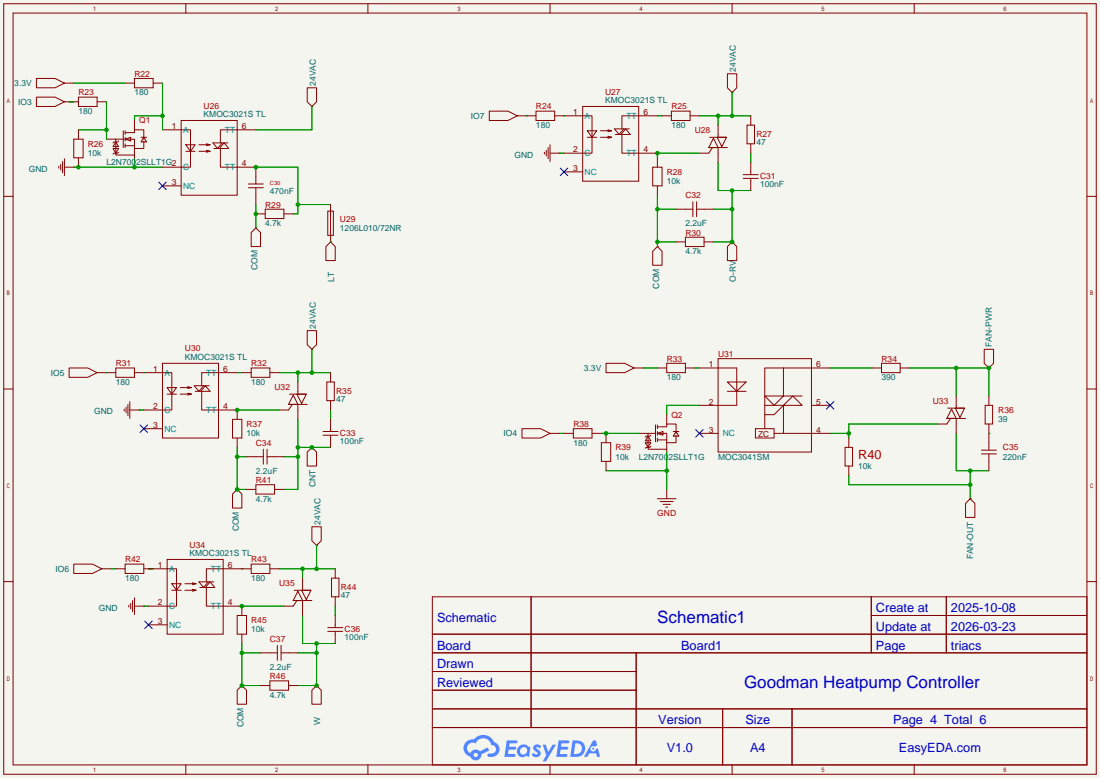
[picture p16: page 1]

Schematic | Schematic1 | Create at | 2025-10-08

Update at | 2026-03-23

Board | Board1 | Page | triacs
Drawn | | Goodman Heatpump Controller
Reviewed

Version | Size | Page 4 Total 6
V1.0 | A4 | EasyEDA.com

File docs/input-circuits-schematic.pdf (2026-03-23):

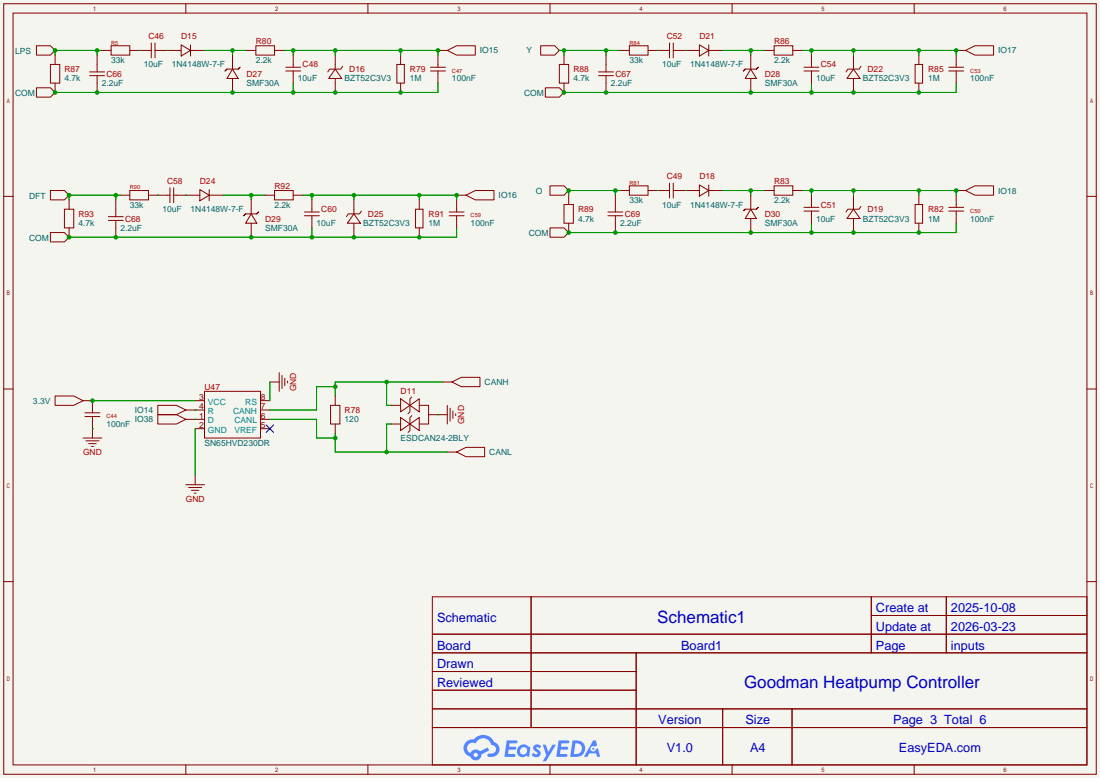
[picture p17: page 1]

Schematic | Schematic1 | Create at | 2025-10-08

Update at | 2026-03-23

Board | Board1 | Page | inputs
Drawn | | Goodman Heatpump Controller
Reviewed

Version | Size | Page 3 Total 6
V1.0 | A4 | EasyEDA.com

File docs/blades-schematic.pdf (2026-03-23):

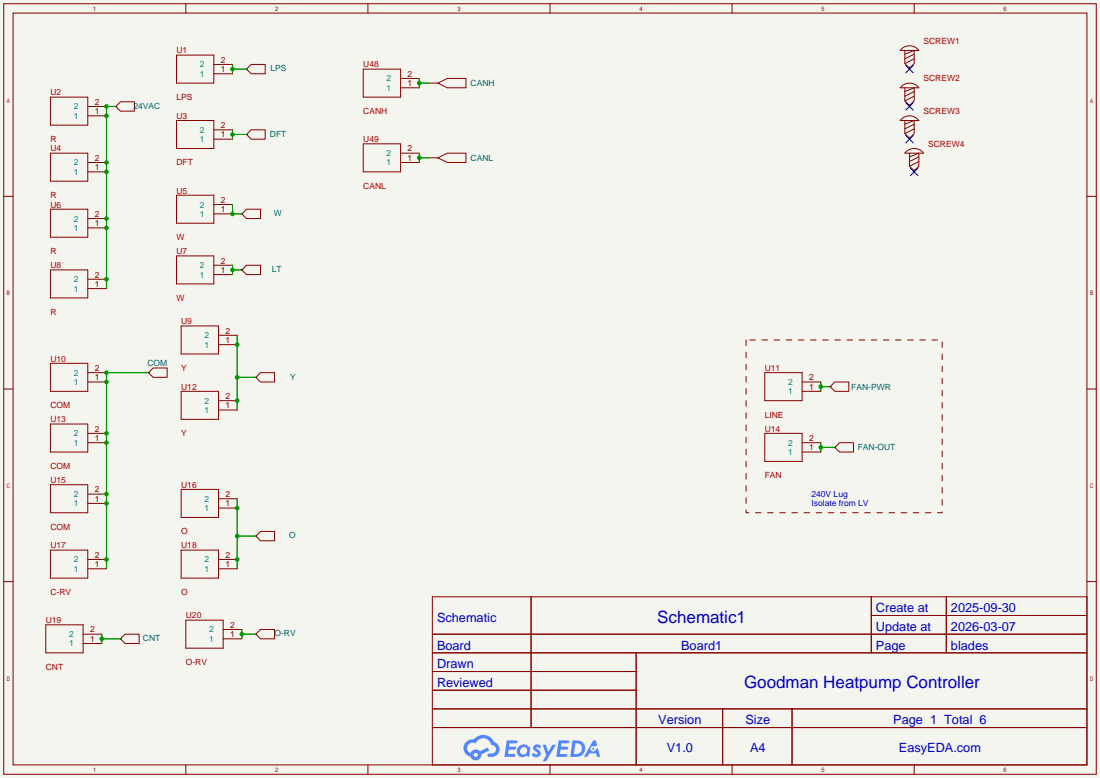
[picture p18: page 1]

Schematic | Schematic1 | Create at | 2025-09-30

Update at | 2026-03-07

Board | Board1 | Page | blades
Drawn | | Goodman Heatpump Controller
Reviewed

Version | Size | Page 1 Total 6
V1.0 | A4 | EasyEDA.com

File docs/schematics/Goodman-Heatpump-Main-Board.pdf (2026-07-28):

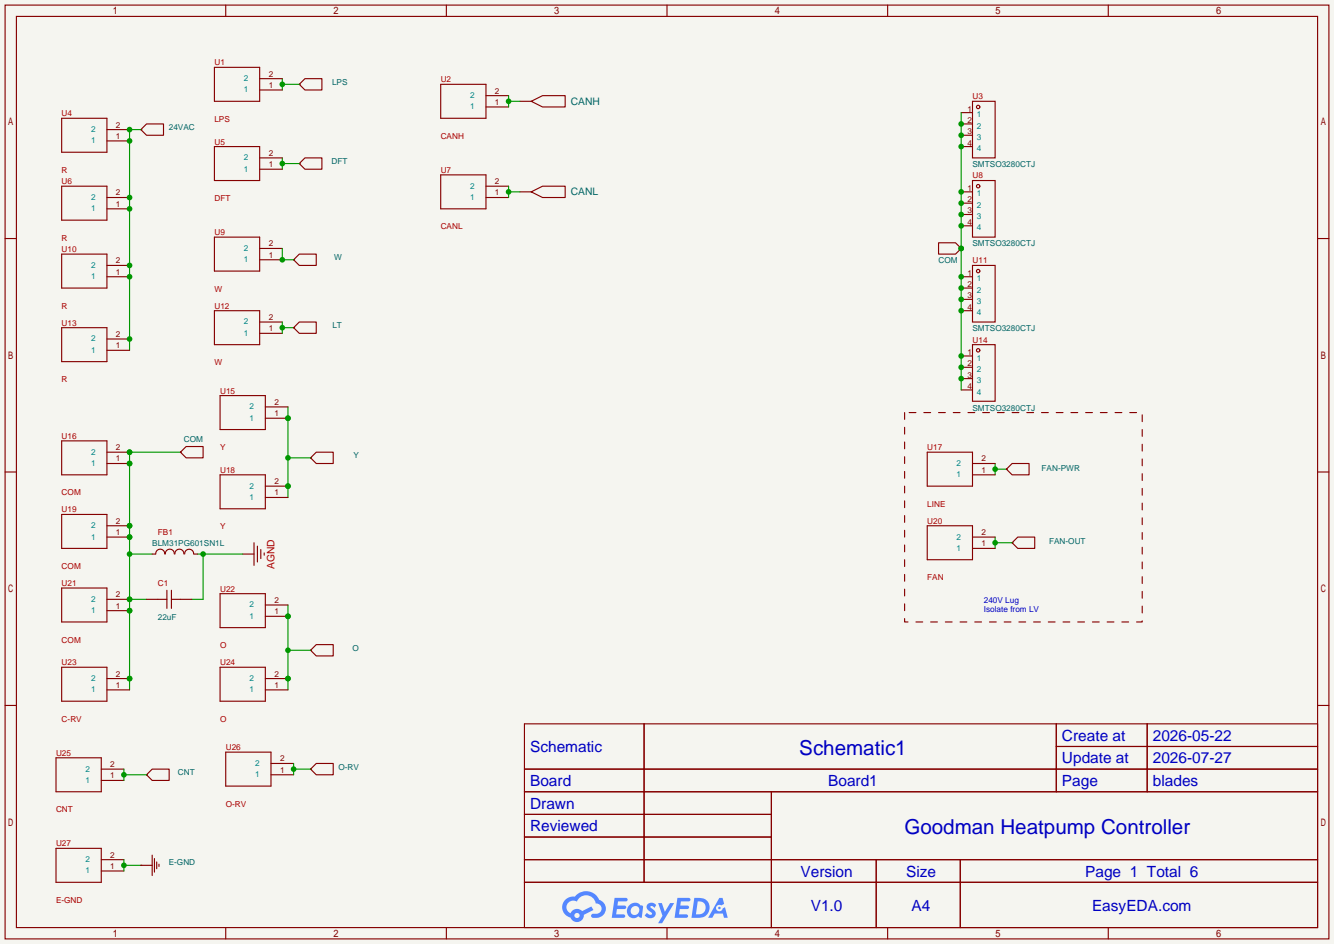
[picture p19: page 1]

Schematic | Schematic1 | Create at | 2026-05-22

Update at | 2026-07-27

Board | Board1 | Page | blades
Drawn | | Goodman Heatpump Controller
Reviewed

Version | Size | Page 1 Total 6
V1.0 | A4 | EasyEDA.com

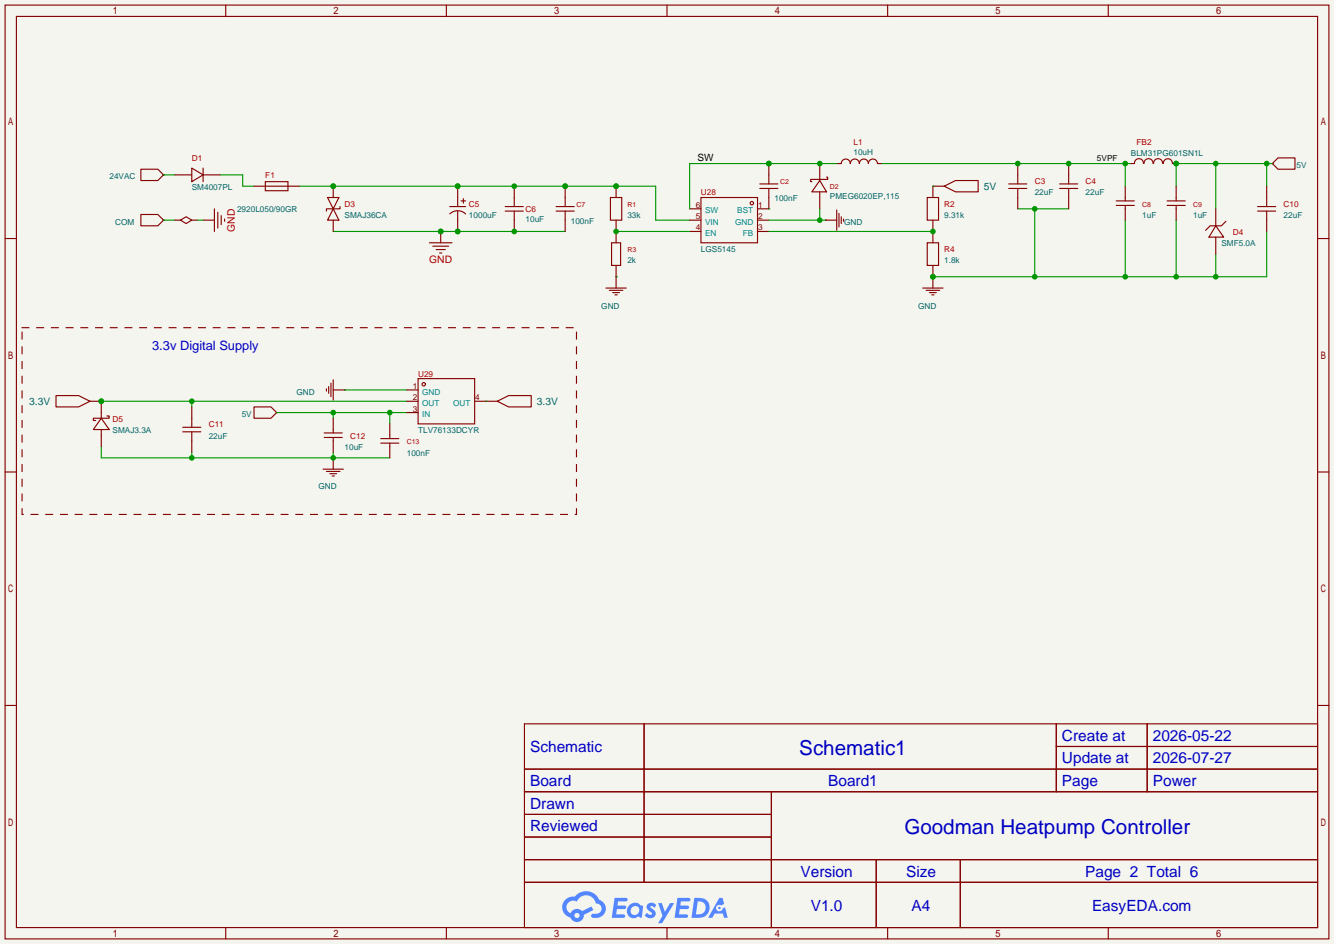
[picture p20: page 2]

Schematic | Schematic1 | Create at | 2026-05-22

Update at | 2026-07-27

Board | Board1 | Page | Power
Drawn | | Goodman Heatpump Controller
Reviewed

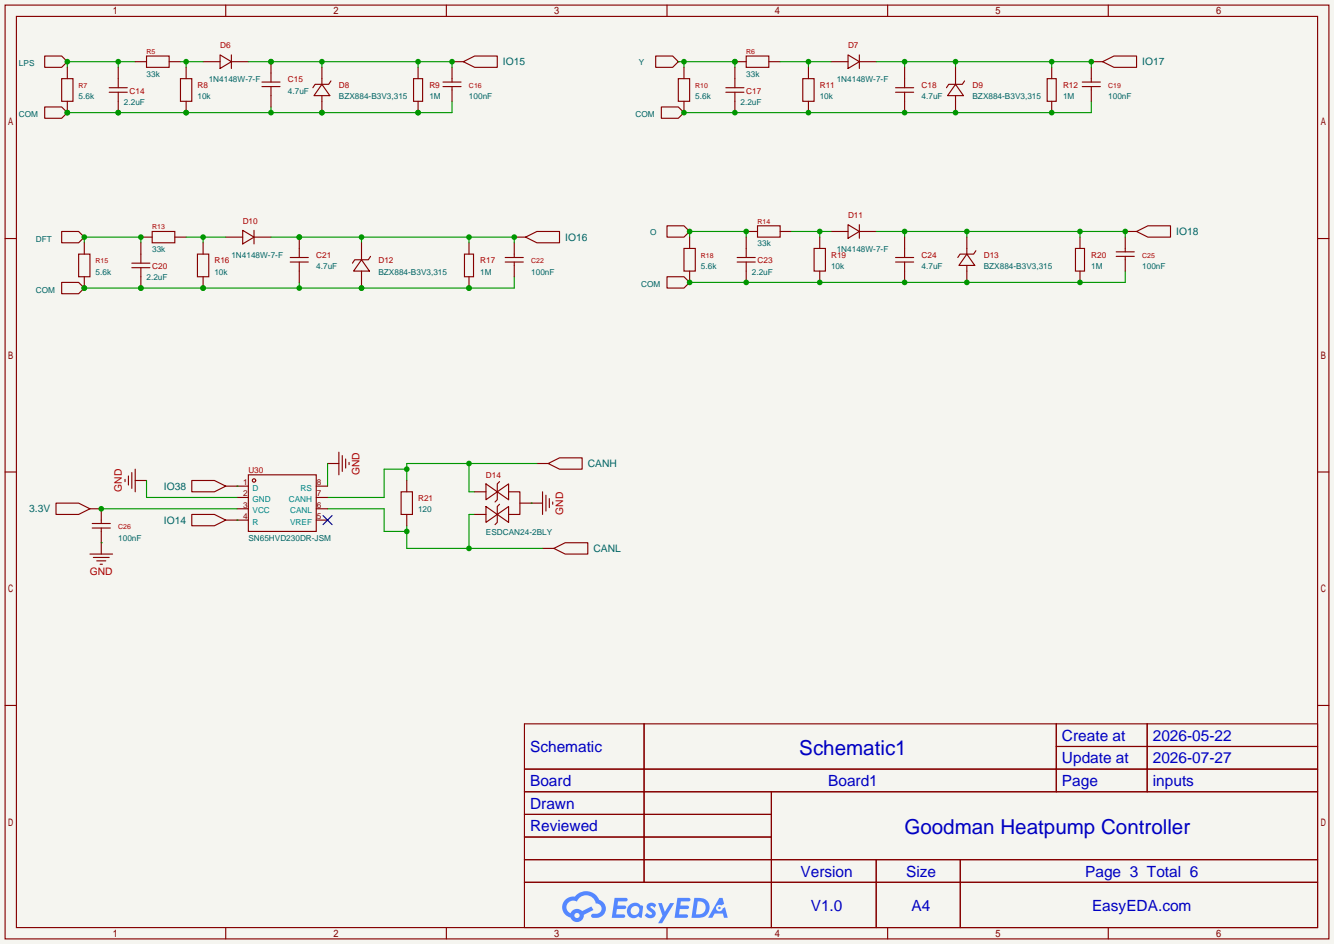
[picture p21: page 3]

Schematic | Schematic1 | Create at | 2026-05-22

Update at | 2026-07-27

Board | Board1 | Page | inputs
Drawn | | Goodman Heatpump Controller
Reviewed

# KMOC3021S TL COM

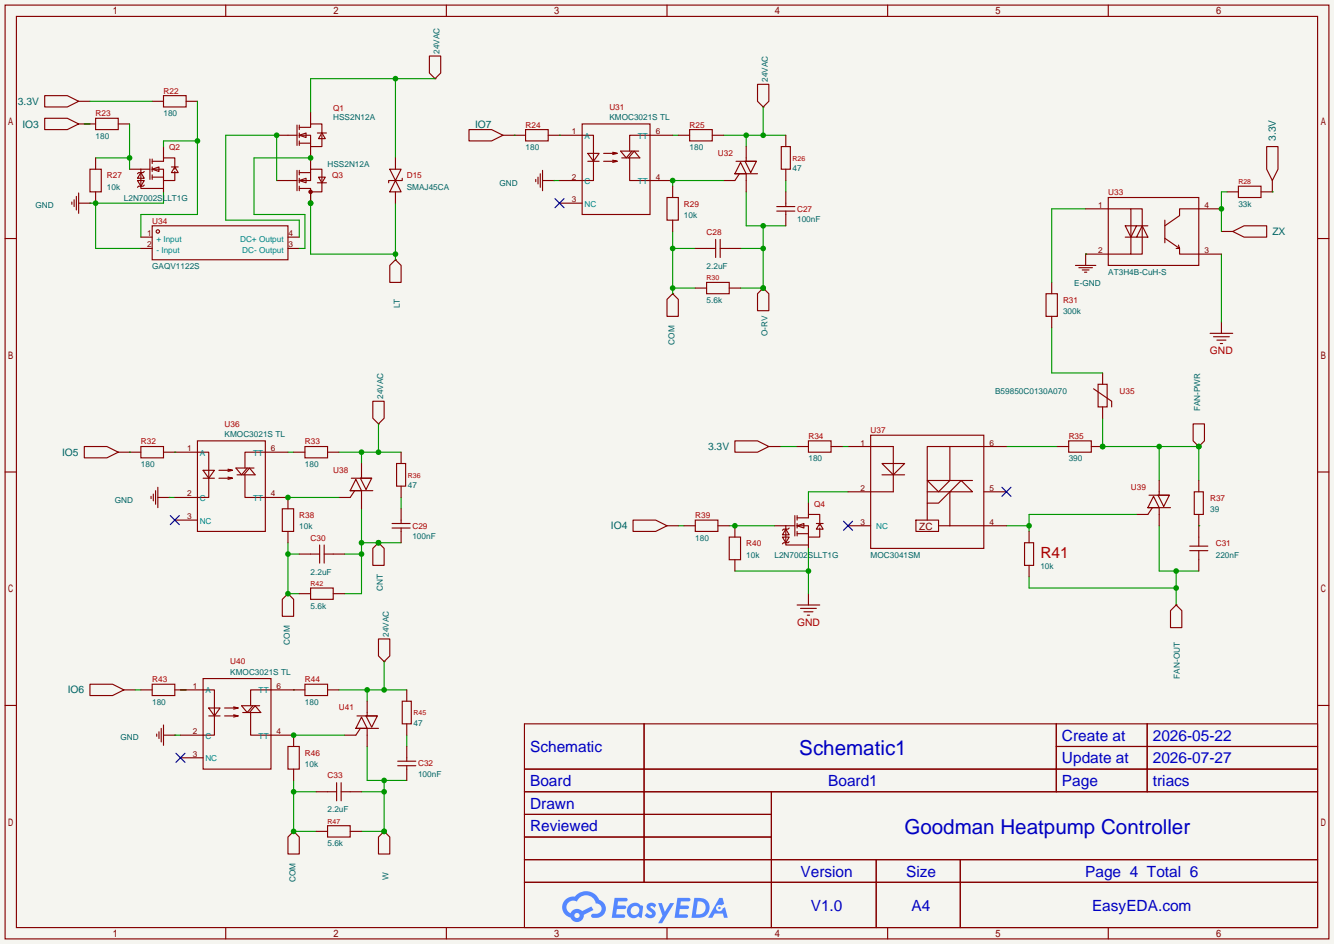
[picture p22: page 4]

Schematic | Schematic1 | Create at | 2026-05-22

Update at | 2026-07-27

Board | Board1 | Page | triacs
Drawn | | Goodman Heatpump Controller
Reviewed

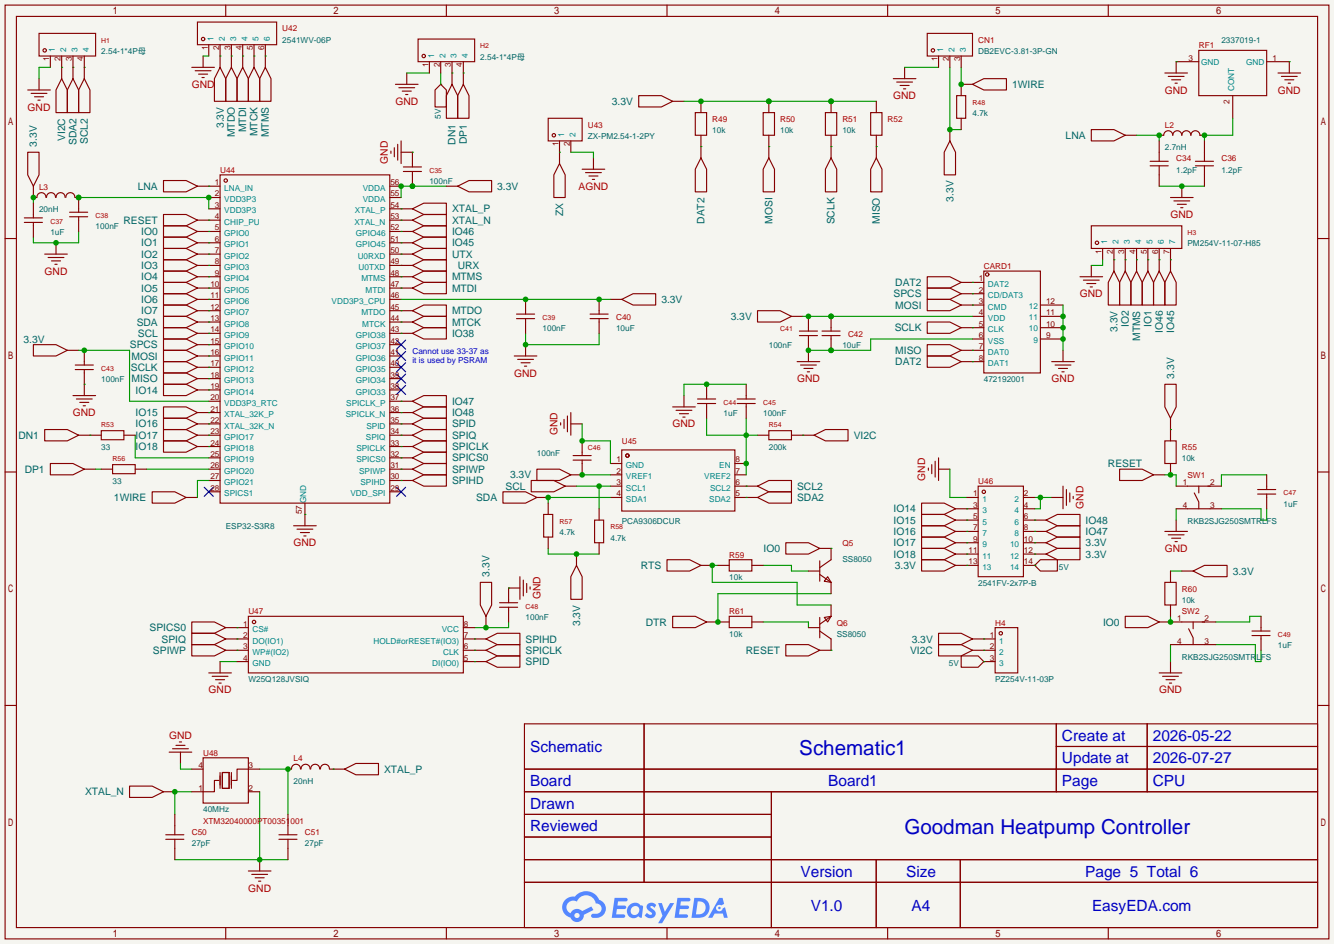
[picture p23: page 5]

Cannot use 33-37 as
it is used by PSRAM

Schematic | Schematic1 | Create at | 2026-05-22

Update at | 2026-07-27

Board | Board1 | Page | CPU
Drawn | | Goodman Heatpump Controller
Reviewed

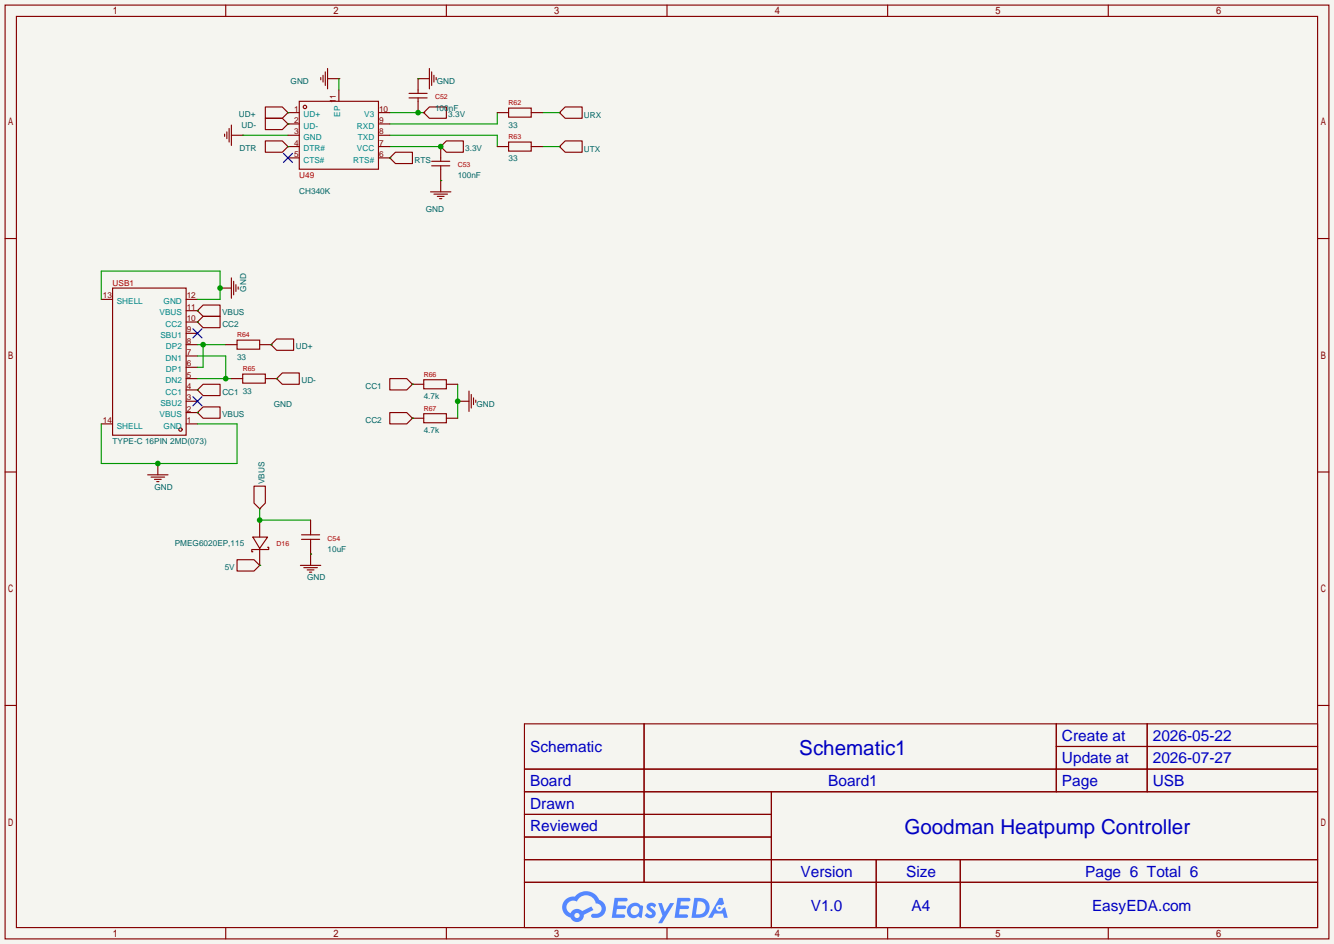
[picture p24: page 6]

Schematic | Schematic1 | Create at | 2026-05-22

Update at | 2026-07-27

Board | Board1 | Page | USB
Drawn | | Goodman Heatpump Controller
Reviewed

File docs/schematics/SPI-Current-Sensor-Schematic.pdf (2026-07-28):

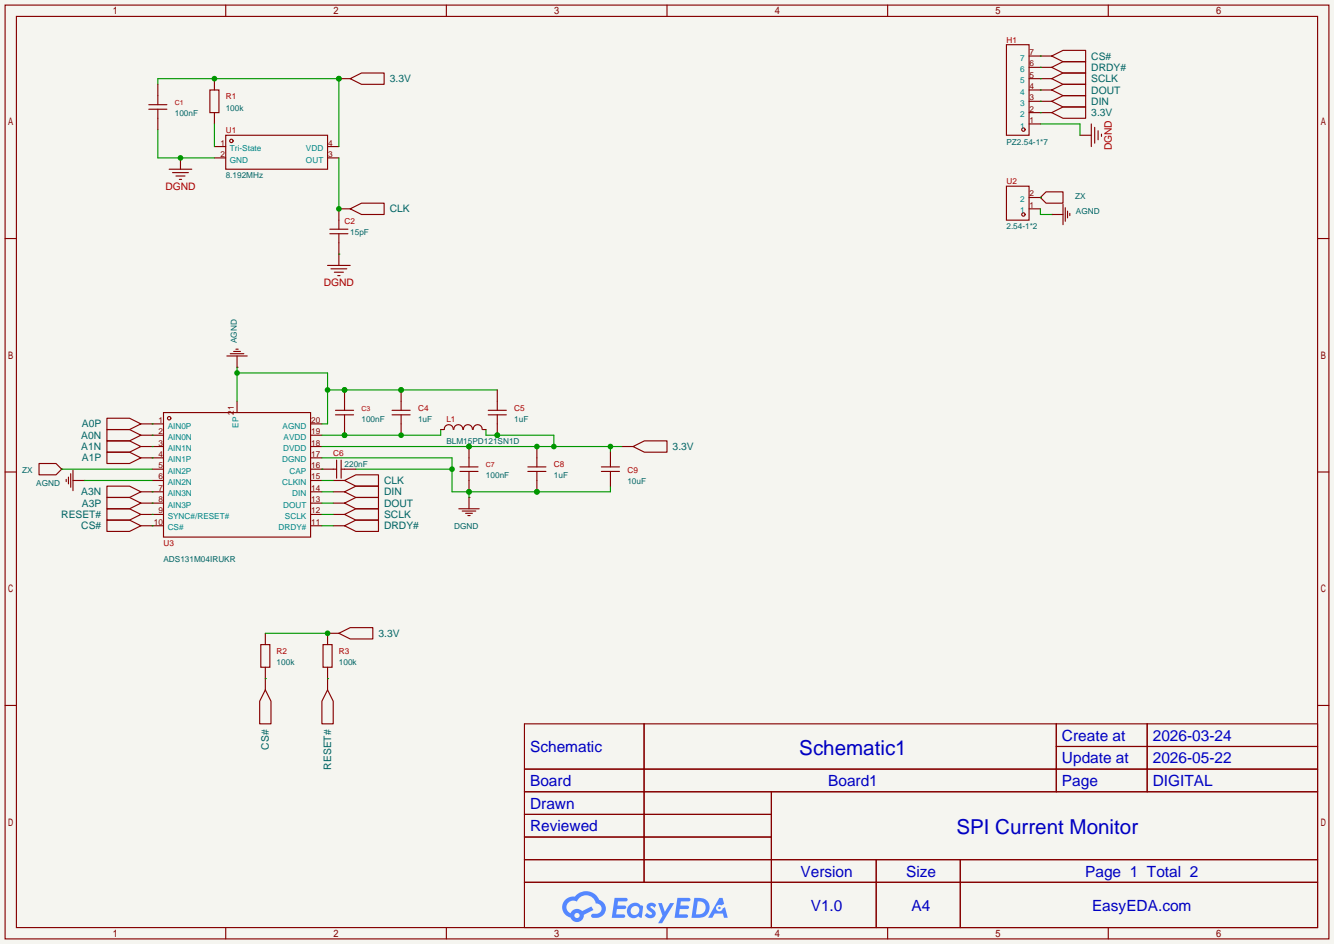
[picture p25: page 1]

Schematic | Schematic1 | Create at | 2026-03-24

Update at | 2026-05-22

Board | Board1 | Page | DIGITAL
Drawn | | SPI Current Monitor
Reviewed

Version | Size | Page 1 Total 2
V1.0 | A4 | EasyEDA.com

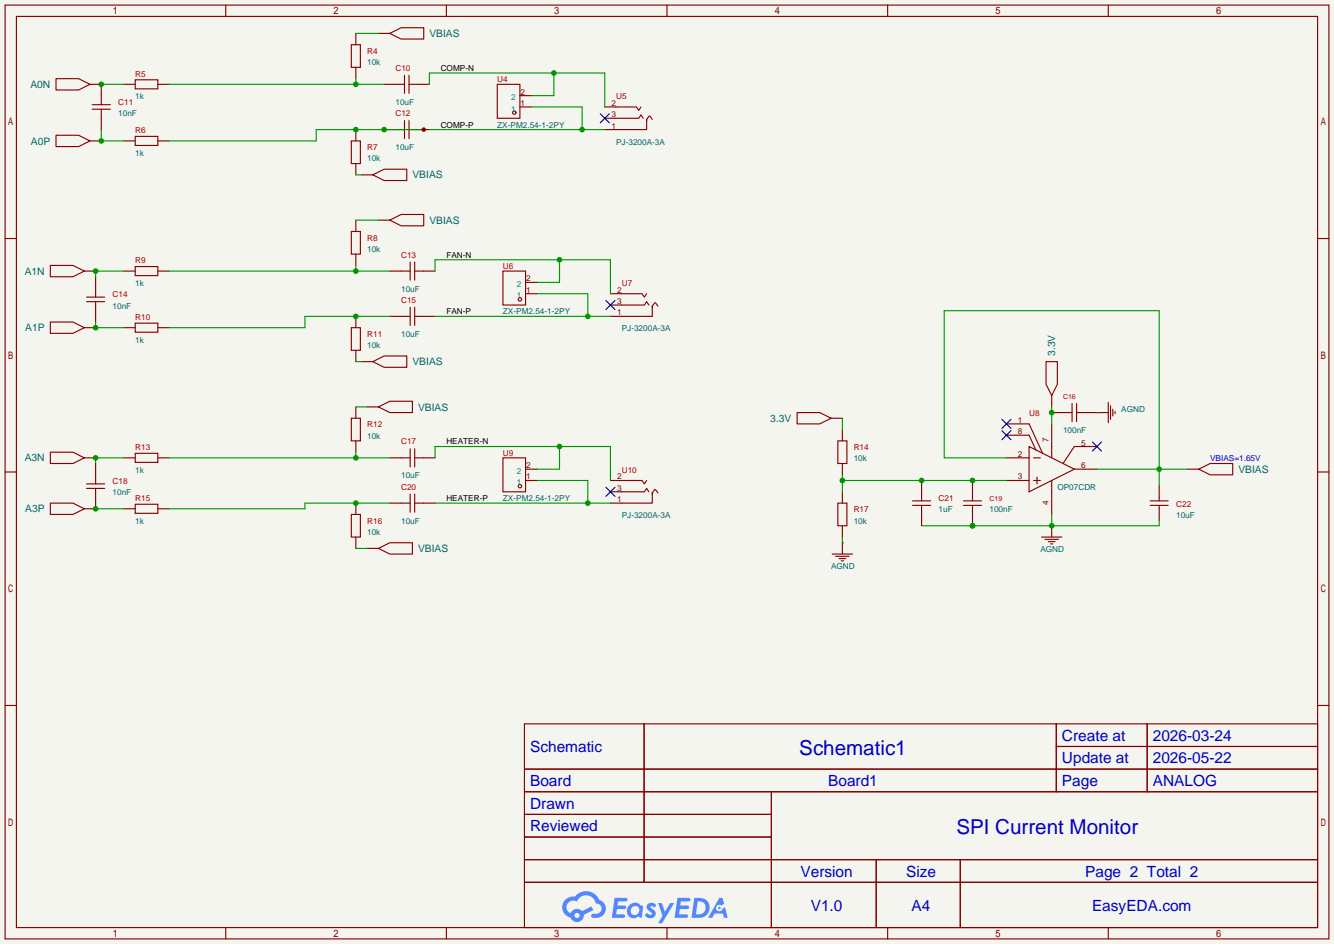
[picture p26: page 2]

Schematic | Schematic1 | Create at | 2026-03-24

Update at | 2026-05-22

Board | Board1 | Page | ANALOG
Drawn | | SPI Current Monitor
Reviewed

Version | Size | Page 2 Total 2
V1.0 | A4 | EasyEDA.com

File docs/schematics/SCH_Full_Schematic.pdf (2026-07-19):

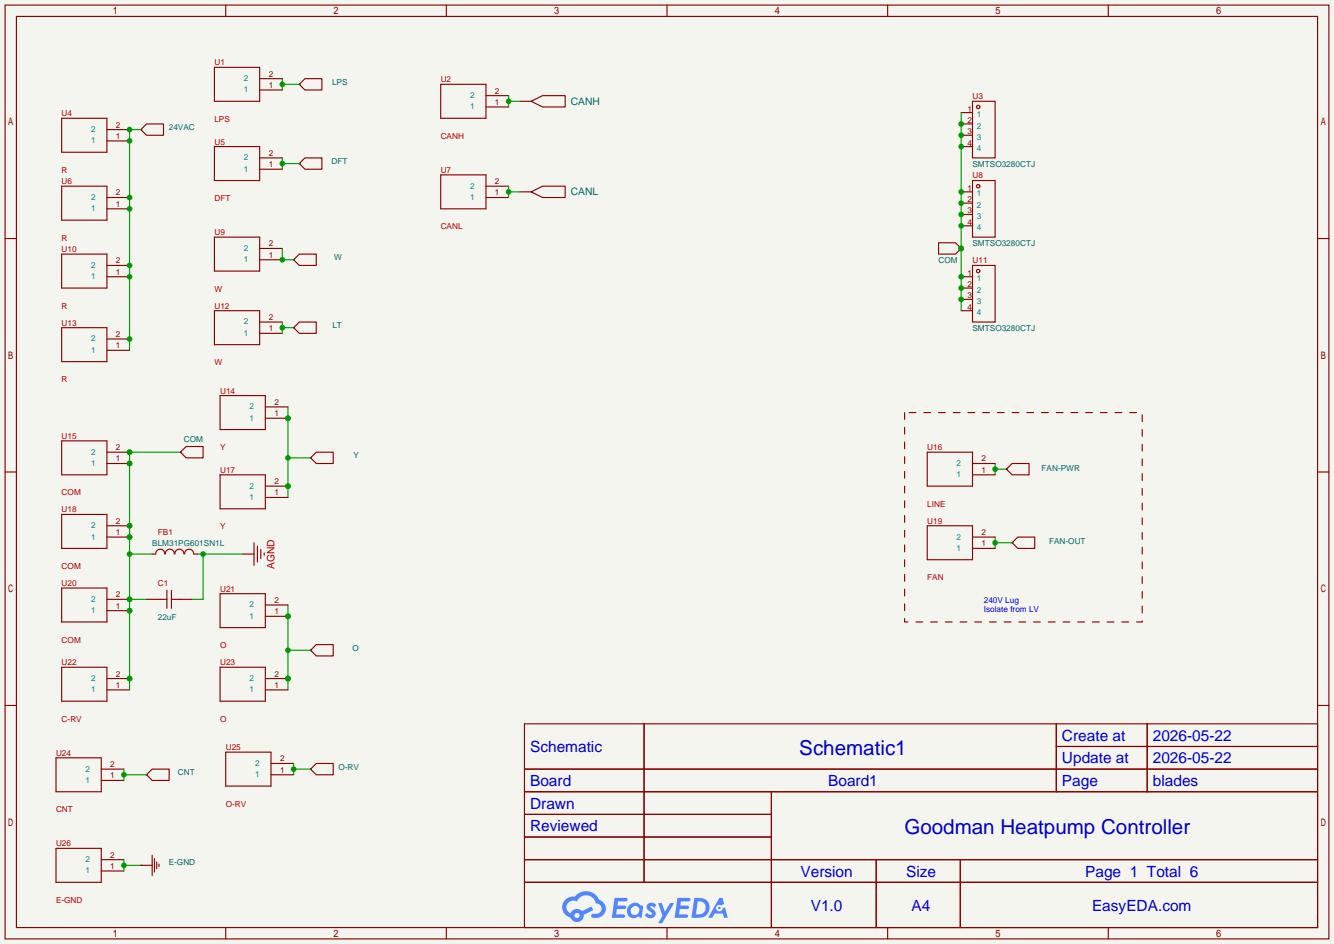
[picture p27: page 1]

Schematic | Schematic1 | Create at | 2026-05-22

Update at | 2026-05-22

Board | Board1 | Page | blades
Drawn | | Goodman Heatpump Controller
Reviewed

Version | Size | Page 1 Total 6
V1.0 | A4 | EasyEDA.com


Schematic | Schematic1 | Create at | 2026-05-22

Update at | 2026-05-22

Board | Board1 | Page | Power
Drawn | | Goodman Heatpump Controller
Reviewed


Schematic | Schematic1 | Create at | 2026-05-22

Update at | 2026-06-16

Board | Board1 | Page | inputs
Drawn | | Goodman Heatpump Controller
Reviewed

# KMOC3021S TL COM


Schematic | Schematic1 | Create at | 2026-05-22

Update at | 2026-06-16

Board | Board1 | Page | triacs
Drawn | | Goodman Heatpump Controller
Reviewed


Cannot use 33-37 as
it is used by PSRAM

Schematic | Schematic1 | Create at | 2026-05-22

Update at | 2026-05-22

Board | Board1 | Page | CPU
Drawn | | Goodman Heatpump Controller
Reviewed


Schematic | Schematic1 | Create at | 2026-05-22

Update at | 2026-05-22

Board | Board1 | Page | USB
Drawn | | Goodman Heatpump Controller
Reviewed

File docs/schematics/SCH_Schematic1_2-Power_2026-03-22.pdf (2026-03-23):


Schematic | Schematic1 | Create at | 2025-10-08

Update at | 2026-03-22

Board | Board1 | Page | Power
Drawn | | Goodman Heatpump Controller
Reviewed

Version | Size | Page 2 Total 6
V1.0 | A4 | EasyEDA.com

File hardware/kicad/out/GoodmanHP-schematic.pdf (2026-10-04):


Rebuilt in KiCad from the EasyEDA v8 netlist
alshowto.com
Sheet: /
File: GoodmanHP.kicad_sch
Title: Goodman Heatpump Controller

Size: A4 | Rev: v8
KiCad E.D.A. 10.0.6 | Id: 1/7


alshowto.com
Sheet: /Blades & mounting/
File: GoodmanHP_blades.kicad_sch
Title: Goodman Heatpump Controller - Blades & mounting


alshowto.com
Sheet: /Power/
File: GoodmanHP_power.kicad_sch
Title: Goodman Heatpump Controller - Power


alshowto.com
Sheet: /Inputs & CAN/
File: GoodmanHP_inputs.kicad_sch
Title: Goodman Heatpump Controller - Inputs & CAN


alshowto.com
Sheet: /Outputs/
File: GoodmanHP_outputs.kicad_sch
Title: Goodman Heatpump Controller - Outputs


alshowto.com
Sheet: /CPU/
File: GoodmanHP_cpu.kicad_sch
Title: Goodman Heatpump Controller - CPU


alshowto.com
Sheet: /USB/
File: GoodmanHP_usb.kicad_sch
Title: Goodman Heatpump Controller - USB

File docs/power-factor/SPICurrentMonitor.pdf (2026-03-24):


Schematic | Schematic1 | Create at | 2026-03-23

Update at | 2026-03-24

Board | Board1 | Page | DIGITAL
Drawn | | SPI Current Monitor
Reviewed

Version | Size | Page 1 Total 2
V1.0 | A4 | EasyEDA.com


Schematic | Schematic1 | Create at | 2026-03-24

Update at | 2026-03-24

Board | Board1 | Page | ANALOG
Drawn | | SPI Current Monitor
Reviewed

Version | Size | Page 2 Total 2
V1.0 | A4 | EasyEDA.com

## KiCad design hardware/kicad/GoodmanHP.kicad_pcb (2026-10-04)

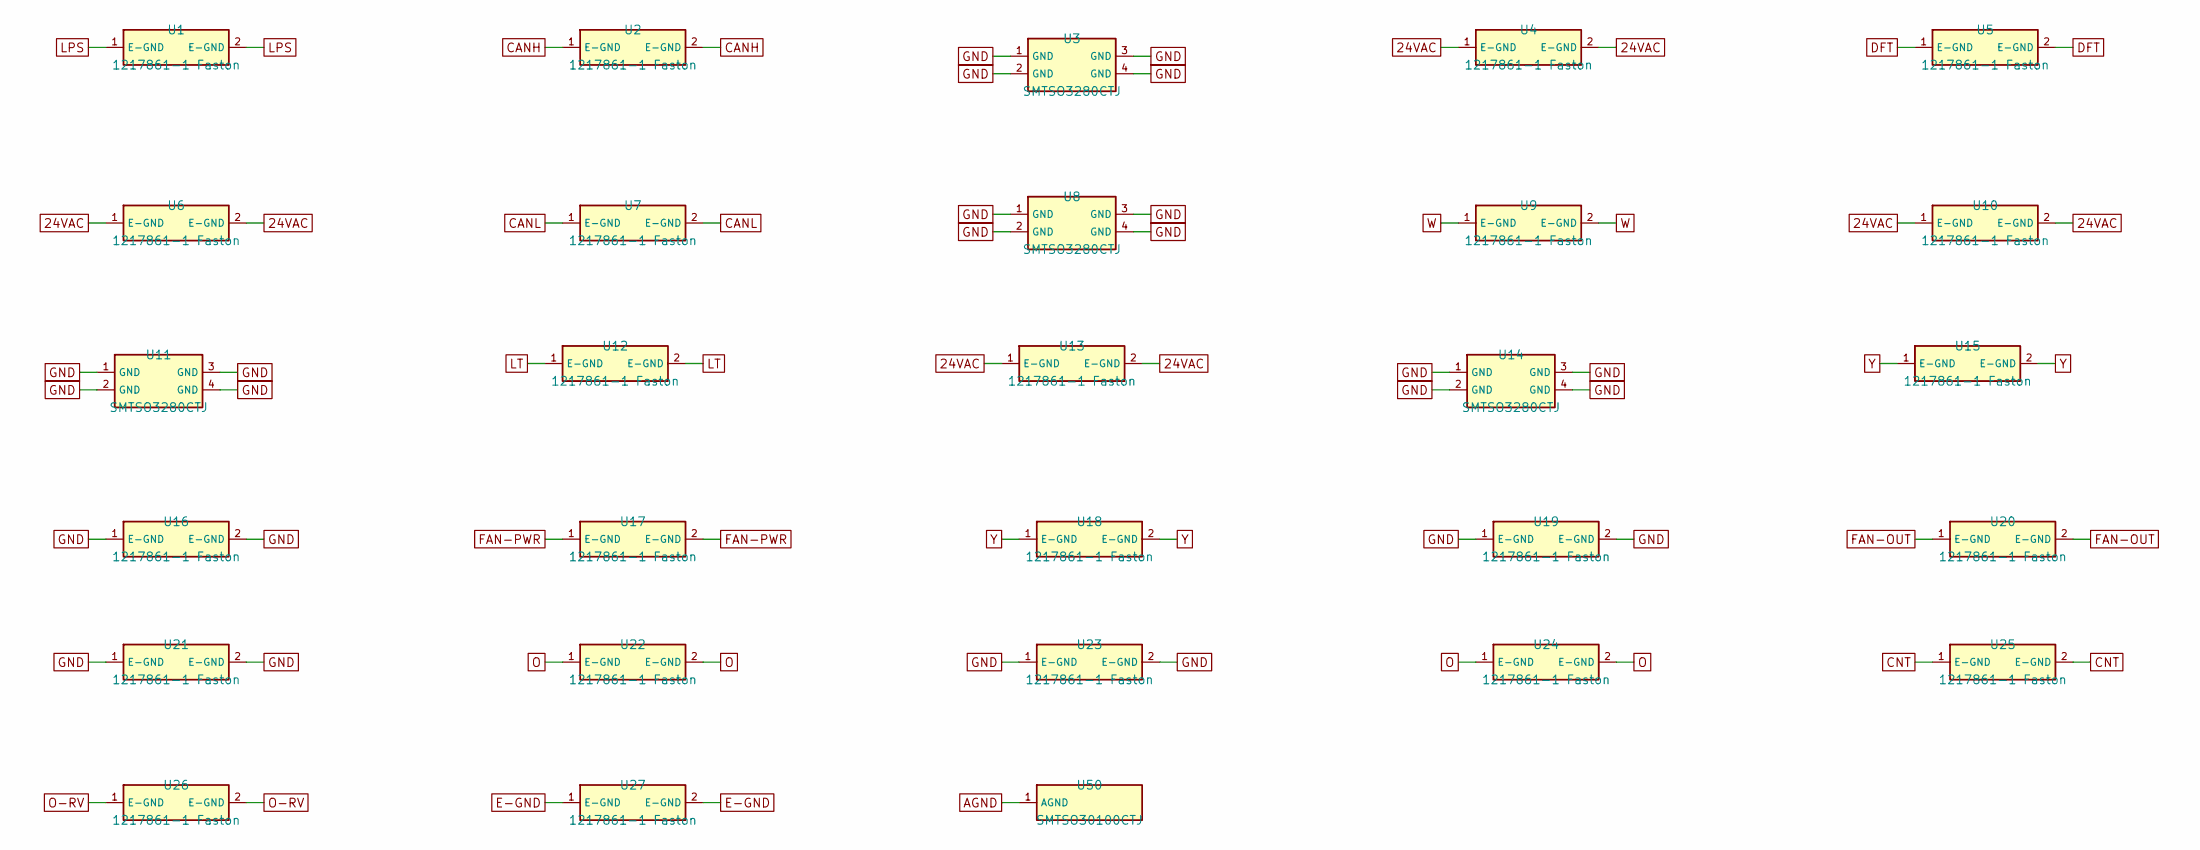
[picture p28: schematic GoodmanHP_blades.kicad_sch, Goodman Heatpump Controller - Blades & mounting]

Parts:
U1, U2, U4, U5, U6, U7, U9, U10, U12, U13, U15, U16, U17, U18, U19, U20, U21, U22, U23, U24, U25, U26, U27: 1217861-1 Faston; 1217861-1; LCSC C428480
U3, U8, U11, U14: SMTSO3280CTJ; SMD_BD5.6-L5.6-W5.6-D4.1; LCSC C2928174
U50: SMTSO30100CTJ; SCREW-SMD_BD5.6-D4.1-H10; LCSC C2916370

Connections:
24VAC: U4.1, U4.2, U6.1, U6.2, U10.1, U10.2, U13.1, U13.2; also elsewhere on the board
AGND: U50.1; also elsewhere on the board
CANH: U2.1, U2.2; also elsewhere on the board
CANL: U7.1, U7.2; also elsewhere on the board
CNT: U25.1, U25.2; also elsewhere on the board
DFT: U5.1, U5.2; also elsewhere on the board
E-GND: U27.1, U27.2; also elsewhere on the board
FAN-OUT: U20.1, U20.2; also elsewhere on the board
FAN-PWR: U17.1, U17.2; also elsewhere on the board
GND: U3.1, U3.2, U3.3, U3.4, U8.1, U8.2, U8.3, U8.4, U11.1, U11.2, U11.3, U11.4, U14.1, U14.2, U14.3, U14.4, U16.1, U16.2, U19.1, U19.2, U21.1, U21.2, U23.1, U23.2; also elsewhere on the board
LPS: U1.1, U1.2; also elsewhere on the board
LT: U12.1, U12.2; also elsewhere on the board
O: U22.1, U22.2, U24.1, U24.2; also elsewhere on the board
O-RV: U26.1, U26.2; also elsewhere on the board
W: U9.1, U9.2; also elsewhere on the board
Y: U15.1, U15.2, U18.1, U18.2; also elsewhere on the board

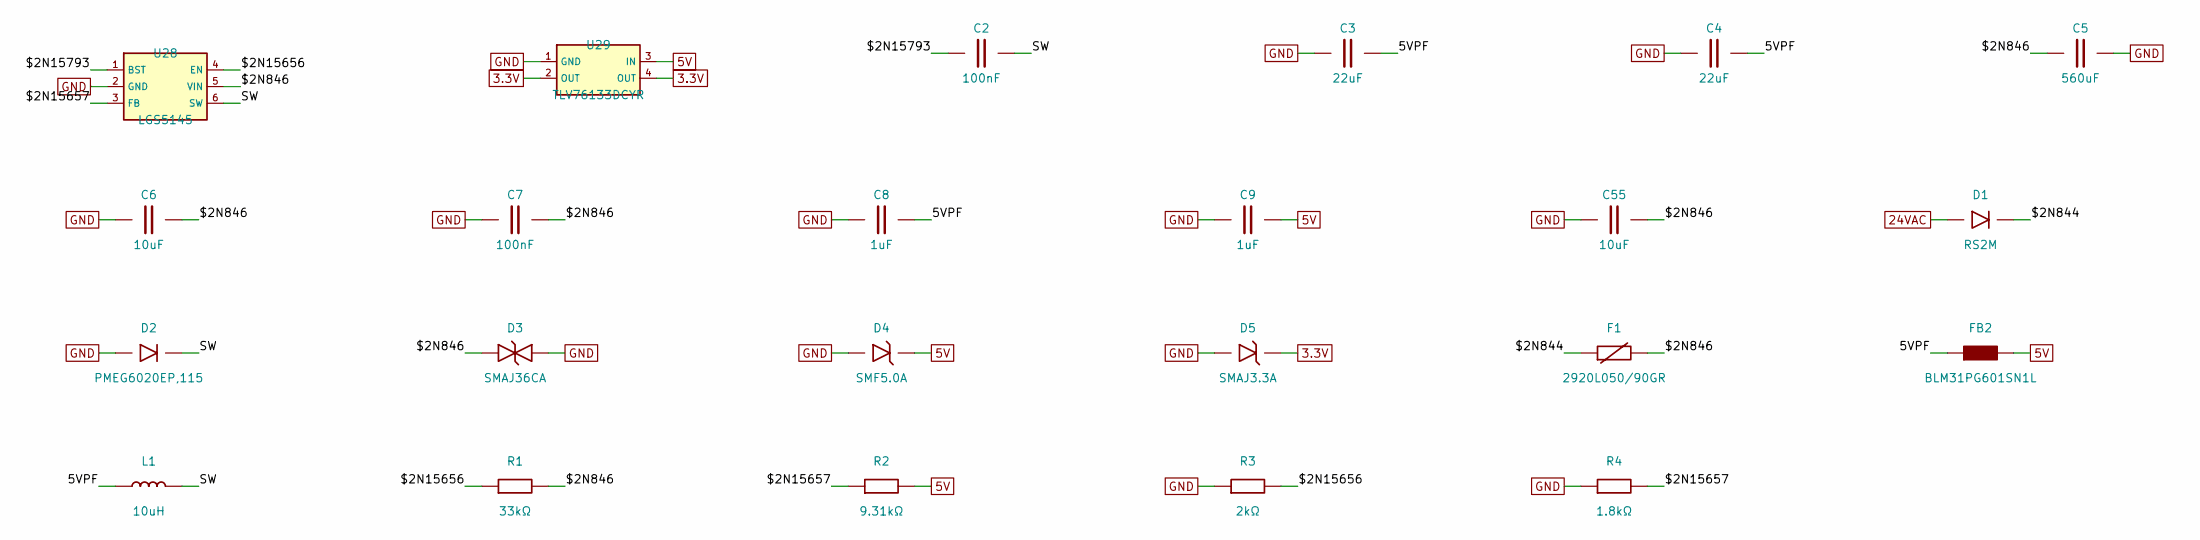
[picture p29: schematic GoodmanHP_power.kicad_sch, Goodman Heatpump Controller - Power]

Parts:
C2, C7: 100nF; C0402; LCSC C77020
C3, C4: 22uF; C0805; LCSC C907991
C5: 560uF; CAP-TH_BD10.0-P5.00-D1.0-FD_1; LCSC C49309240
C6, C55: 10uF; C1210; LCSC C437568
C8, C9: 1uF; C0201; LCSC C76929
D1: RS2M; SMA_L4.3-W2.7-LS5.1-RD; LCSC C908426
D2: PMEG6020EP,115; SOD-128_L3.7-W2.5-LS4.7-FD; LCSC C179433
D3: SMAJ36CA; SMA_L4.2-W2.7-LS5.0-BI; LCSC C908830
D4: SMF5.0A; SOD-123FL_L2.8-W1.9-LS3.7-RD; LCSC C2857263
D5: SMAJ3.3A; SMA_L4.3-W2.7-LS5.1-RD; LCSC C22365220
F1: 2920L050/90GR; F2920; LCSC C41414044
FB2: BLM31PG601SN1L; L1206; LCSC C16902
L1: 10uH; IND-SMD_L2.5-W2.0; LCSC C5832376
R1: 33kΩ; R0201; LCSC C473534
R2: 9.31kΩ; R0201; LCSC C423401
R3: 2kΩ; R0201; LCSC C851709
R4: 1.8kΩ; R0201; LCSC C473568
U28: LGS5145; SOT-23-6_L2.9-W1.7-P0.95-LS2.8-BL; LCSC C5123971
U29: TLV76133DCYR; SOT-223-4_L6.5-W3.5-P2.30-LS7.0-TR; LCSC C7527500

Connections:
3.3V: D5.1 (K), U29.2 (OUT), U29.4 (OUT); also elsewhere on the board
5V: C9.2, D4.1 (K), FB2.2, R2.2, U29.3 (IN); also elsewhere on the board
5VPF: C3.2, C4.2, C8.2, FB2.1, L1.1
24VAC: D1.2 (A); also elsewhere on the board
$2N844: D1.1 (K), F1.1
$2N846: C5.1, C6.2, C7.2, C55.2, D3.1, F1.2, R1.2, U28.5 (VIN)
$2N15656: R1.1, R3.2, U28.4 (EN)
$2N15657: R2.1, R4.2, U28.3 (FB)
$2N15793: C2.1, U28.1 (BST)
GND: C3.1, C4.1, C5.2, C6.1, C7.1, C8.1, C9.1, C55.1, D2.2 (A), D3.2, D4.2 (A), D5.2 (A), R3.1, R4.1, U28.2 (GND), U29.1 (GND); also elsewhere on the board
SW: C2.2, D2.1 (K), L1.2, U28.6 (SW)

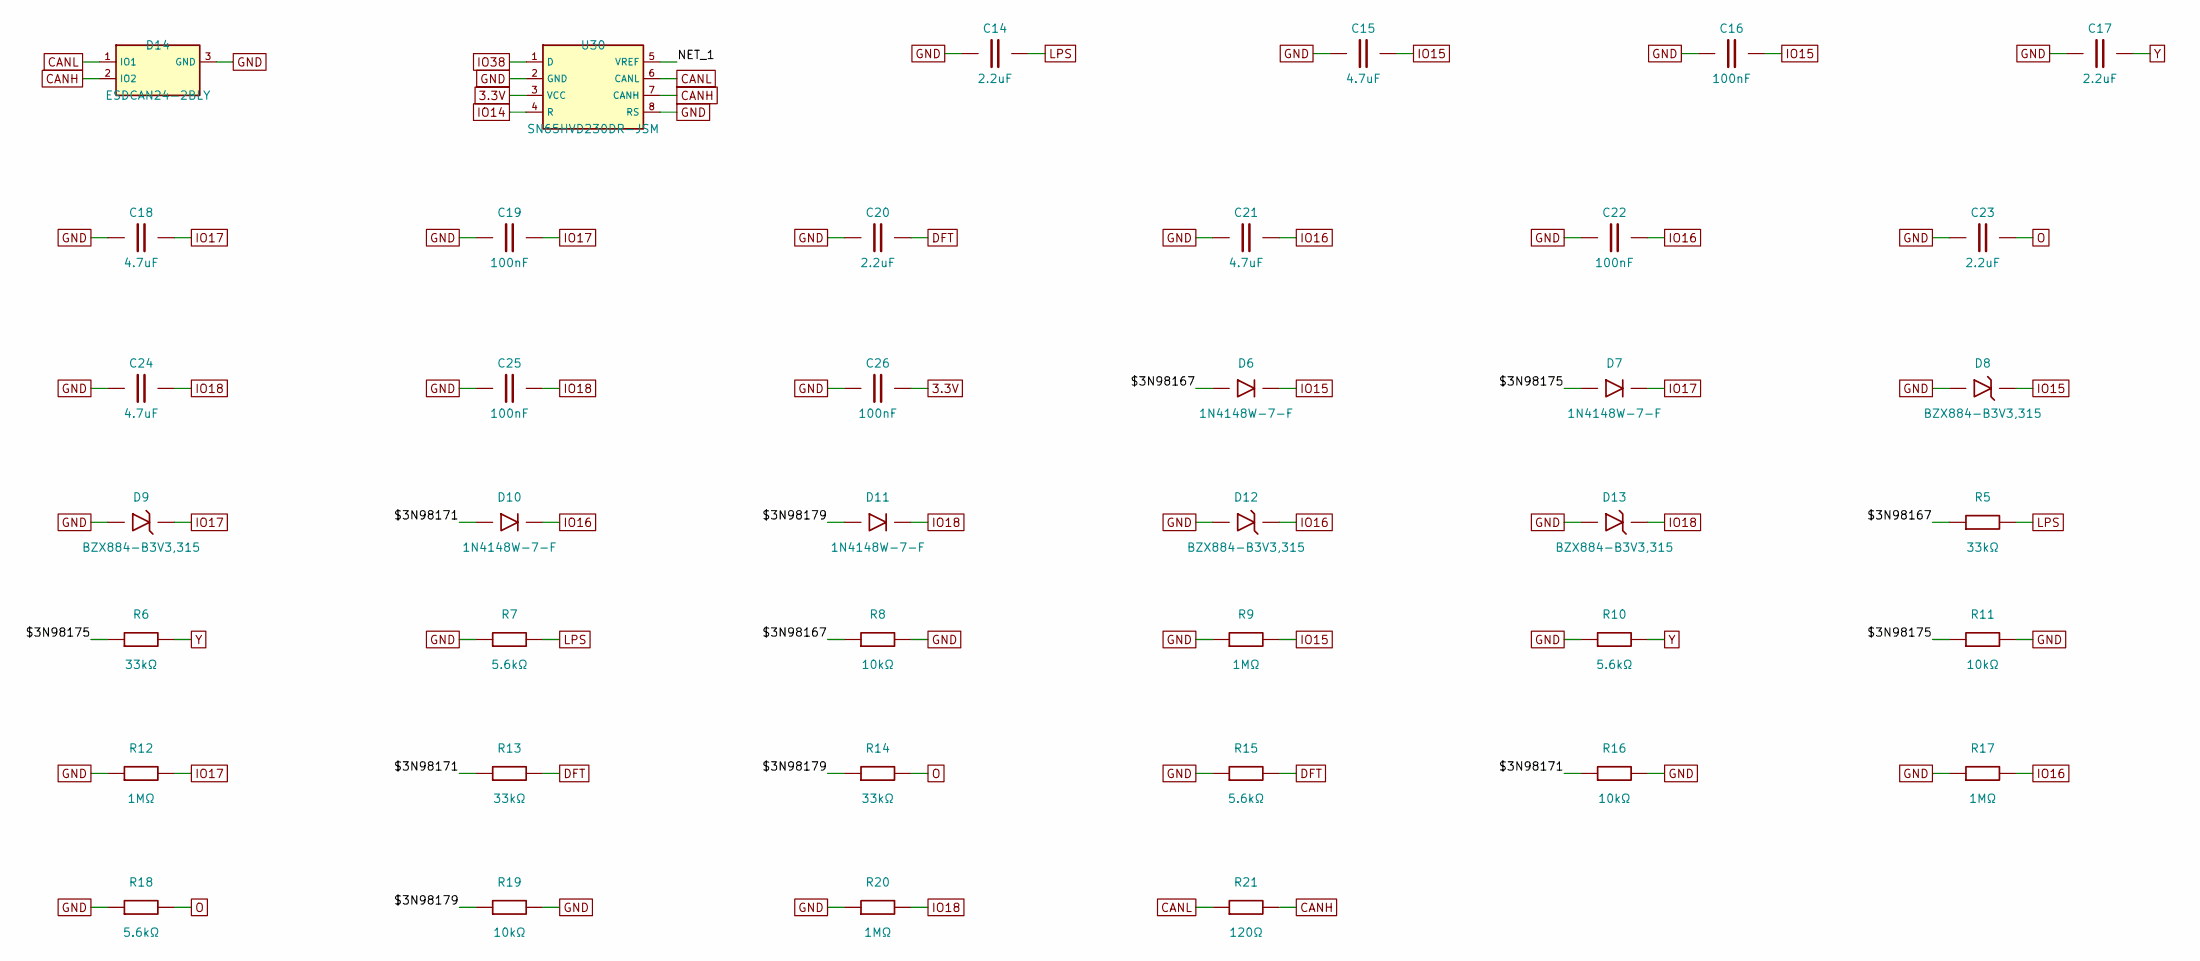
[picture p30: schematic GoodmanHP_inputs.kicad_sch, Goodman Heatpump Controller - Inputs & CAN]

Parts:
C14, C17, C20, C23: 2.2uF; C0805; LCSC C22367838
C15, C18, C21, C24: 4.7uF; C0402; LCSC C20624278
C16, C19, C22, C25, C26: 100nF; C0201; LCSC C85923
D6, D7, D10, D11: 1N4148W-7-F; SOD-123_L2.7-W1.6-LS3.7-RD-1; LCSC C83528
D8, D9, D12, D13: BZX884-B3V3,315; SOD-882_L1.0-W0.6-RD; LCSC C551199
D14: ESDCAN24-2BLY; SOT-23-3_L2.9-W1.3-P1.90-LS2.4-BL-2; LCSC C2937021
R5, R6, R13, R14: 33kΩ; R0201; LCSC C473534
R7, R10, R15, R18: 5.6kΩ; R0805; LCSC C441985
R8, R11, R16, R19: 10kΩ; R0201; LCSC C473048
R9, R12, R17, R20: 1MΩ; R0201; LCSC C295786
R21: 120Ω; R0805; LCSC C844392
U30: SN65HVD230DR-JSM; SOP-8_L4.9-W3.9-P1.27-LS6.0-BL; LCSC C46596299

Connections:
3.3V: C26.2, U30.3 (VCC); also elsewhere on the board
$3N98167: D6.2 (A), R5.1, R8.1
$3N98171: D10.2 (A), R13.1, R16.1
$3N98175: D7.2 (A), R6.1, R11.1
$3N98179: D11.2 (A), R14.1, R19.1
CANH: D14.2 (IO2), R21.2, U30.7 (CANH); also elsewhere on the board
CANL: D14.1 (IO1), R21.1, U30.6 (CANL); also elsewhere on the board
DFT: C20.2, R13.2, R15.2; also elsewhere on the board
GND: C14.1, C15.1, C16.1, C17.1, C18.1, C19.1, C20.1, C21.1, C22.1, C23.1, C24.1, C25.1, C26.1, D8.2 (A), D9.2 (A), D12.2 (A), D13.2 (A), D14.3 (GND), R7.1, R8.2, R9.1, R10.1, R11.2, R12.1, R15.1, R16.2, R17.1, R18.1, R19.2, R20.1, U30.2 (GND), U30.8 (RS); also elsewhere on the board
IO14: U30.4 (R); also elsewhere on the board
IO15: C15.2, C16.2, D6.1 (K), D8.1 (K), R9.2; also elsewhere on the board
IO16: C21.2, C22.2, D10.1 (K), D12.1 (K), R17.2; also elsewhere on the board
IO17: C18.2, C19.2, D7.1 (K), D9.1 (K), R12.2; also elsewhere on the board
IO18: C24.2, C25.2, D11.1 (K), D13.1 (K), R20.2; also elsewhere on the board
IO38: U30.1 (D); also elsewhere on the board
LPS: C14.2, R5.2, R7.2; also elsewhere on the board
NET_1: U30.5 (VREF)
O: C23.2, R14.2, R18.2; also elsewhere on the board
Y: C17.2, R6.2, R10.2; also elsewhere on the board

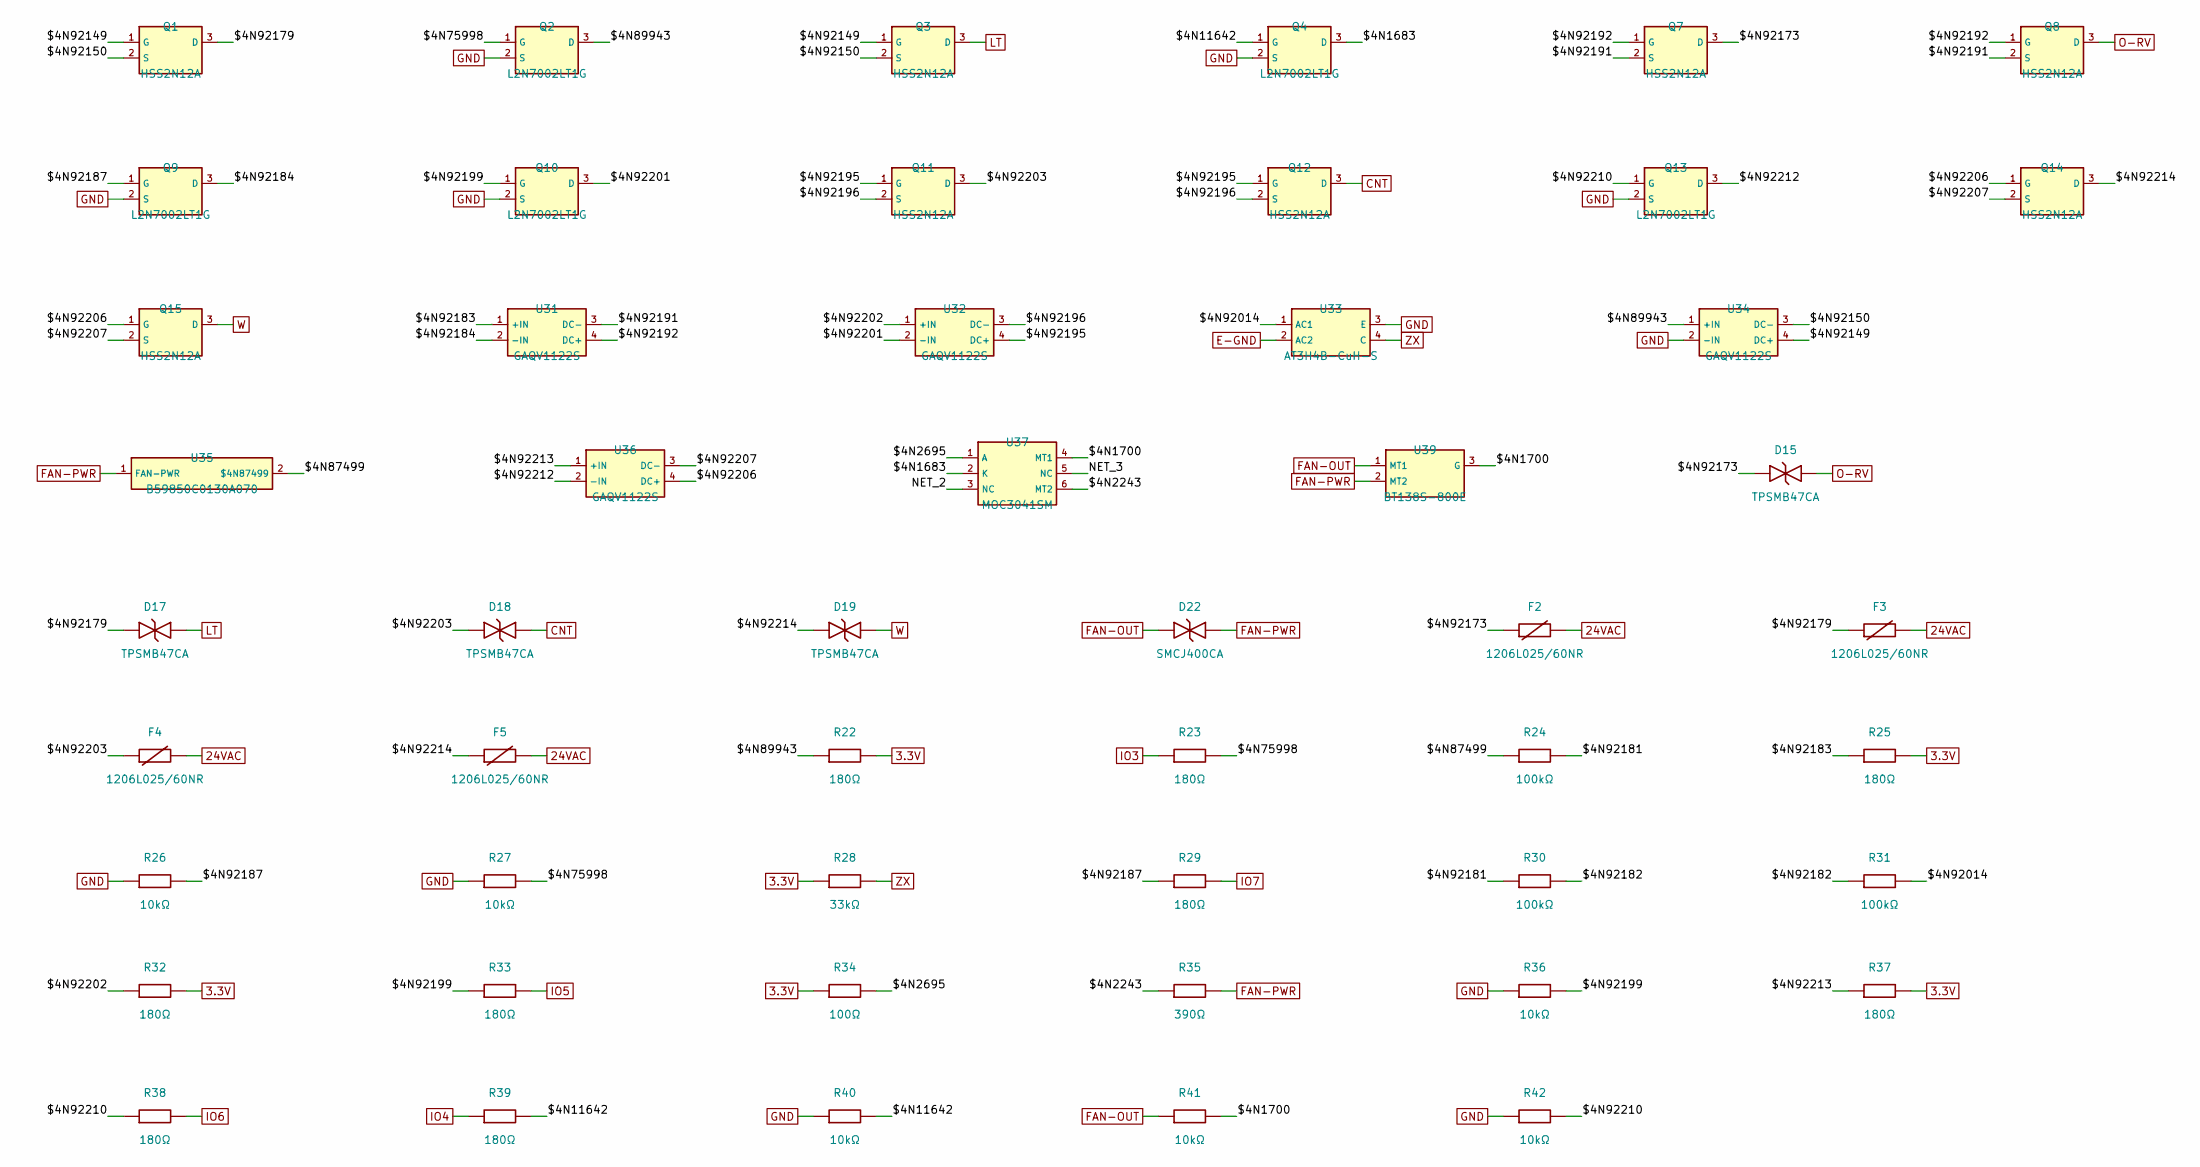
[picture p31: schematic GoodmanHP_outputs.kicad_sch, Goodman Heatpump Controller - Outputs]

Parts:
D15, D17, D18, D19: TPSMB47CA; SMB_L4.3-W3.6-LS5.4-BI; LCSC C1975322
D22: SMCJ400CA; SMCG_L6.8-W5.8-LS7.9-BI; LCSC C5294118
F2, F3, F4, F5: 1206L025/60NR; F1206; LCSC C47345582
Q1, Q3, Q7, Q8, Q11, Q12, Q14, Q15: HSS2N12A; SOT-23-3_L3.0-W1.7-P0.95-LS2.9-BR; LCSC C53243986
Q2, Q4, Q9, Q10, Q13: L2N7002LT1G; SOT-23_L2.9-W1.3-P1.90-LS2.4-BR; LCSC C12779
R22, R23, R25, R29, R32, R33, R37, R38, R39: 180Ω; R0201; LCSC C965335
R24, R30, R31: 100kΩ; R0805_NEW; LCSC C96346
R26, R27, R36, R40, R42: 10kΩ; R0201; LCSC C473048
R28: 33kΩ; R0201; LCSC C473534
R34: 100Ω; R0201; LCSC C77623
R35: 390Ω; R1210; LCSC C2960731
R41: 10kΩ; R0603; LCSC C2906982
U31, U32, U34, U36: GAQV1122S; SOP-4_L4.3-W4.4-P2.54-LS6.8-TR; LCSC C22385006
U33: AT3H4B-CuH-S; SSOP-4_L2.7-W4.6-P1.27-LS7.0-TL; LCSC C20612635
U35: B59850C0130A070; RES-TH_L11.0-W5.0-P5.00-D0.8; LCSC C125471
U37: MOC3041SM; SMD-6_L8.8-W6.4-P2.54-LS9.4-BL; LCSC C22373366
U39: BT138S-800E; TO-252-2_L6.6-W6.1-P4.57-LS10.1-BR-CW; LCSC C5380690

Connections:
3.3V: R22.2, R25.2, R28.1, R32.2, R34.1, R37.2; also elsewhere on the board
24VAC: F2.2, F3.2, F4.2, F5.2; also elsewhere on the board
$4N1683: Q4.3 (D), U37.2 (K)
$4N1700: R41.2, U37.4 (MT1), U39.3 (G)
$4N2243: R35.1, U37.6 (MT2)
$4N2695: R34.2, U37.1 (A)
$4N11642: Q4.1 (G), R39.2, R40.2
$4N75998: Q2.1 (G), R23.2, R27.2
$4N87499: R24.1, U35.2 ($4N87499)
$4N89943: Q2.3 (D), R22.1, U34.1 (+IN)
$4N92014: R31.2, U33.1 (AC1)
$4N92149: Q1.1 (G), Q3.1 (G), U34.4 (DC+)
$4N92150: Q1.2 (S), Q3.2 (S), U34.3 (DC-)
$4N92173: D15.1, F2.1, Q7.3 (D)
$4N92179: D17.1, F3.1, Q1.3 (D)
$4N92181: R24.2, R30.1
$4N92182: R30.2, R31.1
$4N92183: R25.1, U31.1 (+IN)
$4N92184: Q9.3 (D), U31.2 (-IN)
$4N92187: Q9.1 (G), R26.2, R29.1
$4N92191: Q7.2 (S), Q8.2 (S), U31.3 (DC-)
$4N92192: Q7.1 (G), Q8.1 (G), U31.4 (DC+)
$4N92195: Q11.1 (G), Q12.1 (G), U32.4 (DC+)
$4N92196: Q11.2 (S), Q12.2 (S), U32.3 (DC-)
$4N92199: Q10.1 (G), R33.1, R36.2
$4N92201: Q10.3 (D), U32.2 (-IN)
$4N92202: R32.1, U32.1 (+IN)
$4N92203: D18.1, F4.1, Q11.3 (D)
$4N92206: Q14.1 (G), Q15.1 (G), U36.4 (DC+)
$4N92207: Q14.2 (S), Q15.2 (S), U36.3 (DC-)
$4N92210: Q13.1 (G), R38.1, R42.2
$4N92212: Q13.3 (D), U36.2 (-IN)
$4N92213: R37.1, U36.1 (+IN)
$4N92214: D19.1, F5.1, Q14.3 (D)
CNT: D18.2, Q12.3 (D); also elsewhere on the board
E-GND: U33.2 (AC2); also elsewhere on the board
FAN-OUT: D22.1, R41.1, U39.1 (MT1); also elsewhere on the board
FAN-PWR: D22.2, R35.2, U35.1 (FAN-PWR), U39.2 (MT2); also elsewhere on the board
GND: Q2.2 (S), Q4.2 (S), Q9.2 (S), Q10.2 (S), Q13.2 (S), R26.1, R27.1, R36.1, R40.1, R42.1, U33.3 (E), U34.2 (-IN); also elsewhere on the board
IO3: R23.1; also elsewhere on the board
IO4: R39.1; also elsewhere on the board
IO5: R33.2; also elsewhere on the board
IO6: R38.2; also elsewhere on the board
IO7: R29.2; also elsewhere on the board
LT: D17.2, Q3.3 (D); also elsewhere on the board
NET_2: U37.3 (NC)
NET_3: U37.5 (NC)
O-RV: D15.2, Q8.3 (D); also elsewhere on the board
W: D19.2, Q15.3 (D); also elsewhere on the board
ZX: R28.2, U33.4 (C); also elsewhere on the board

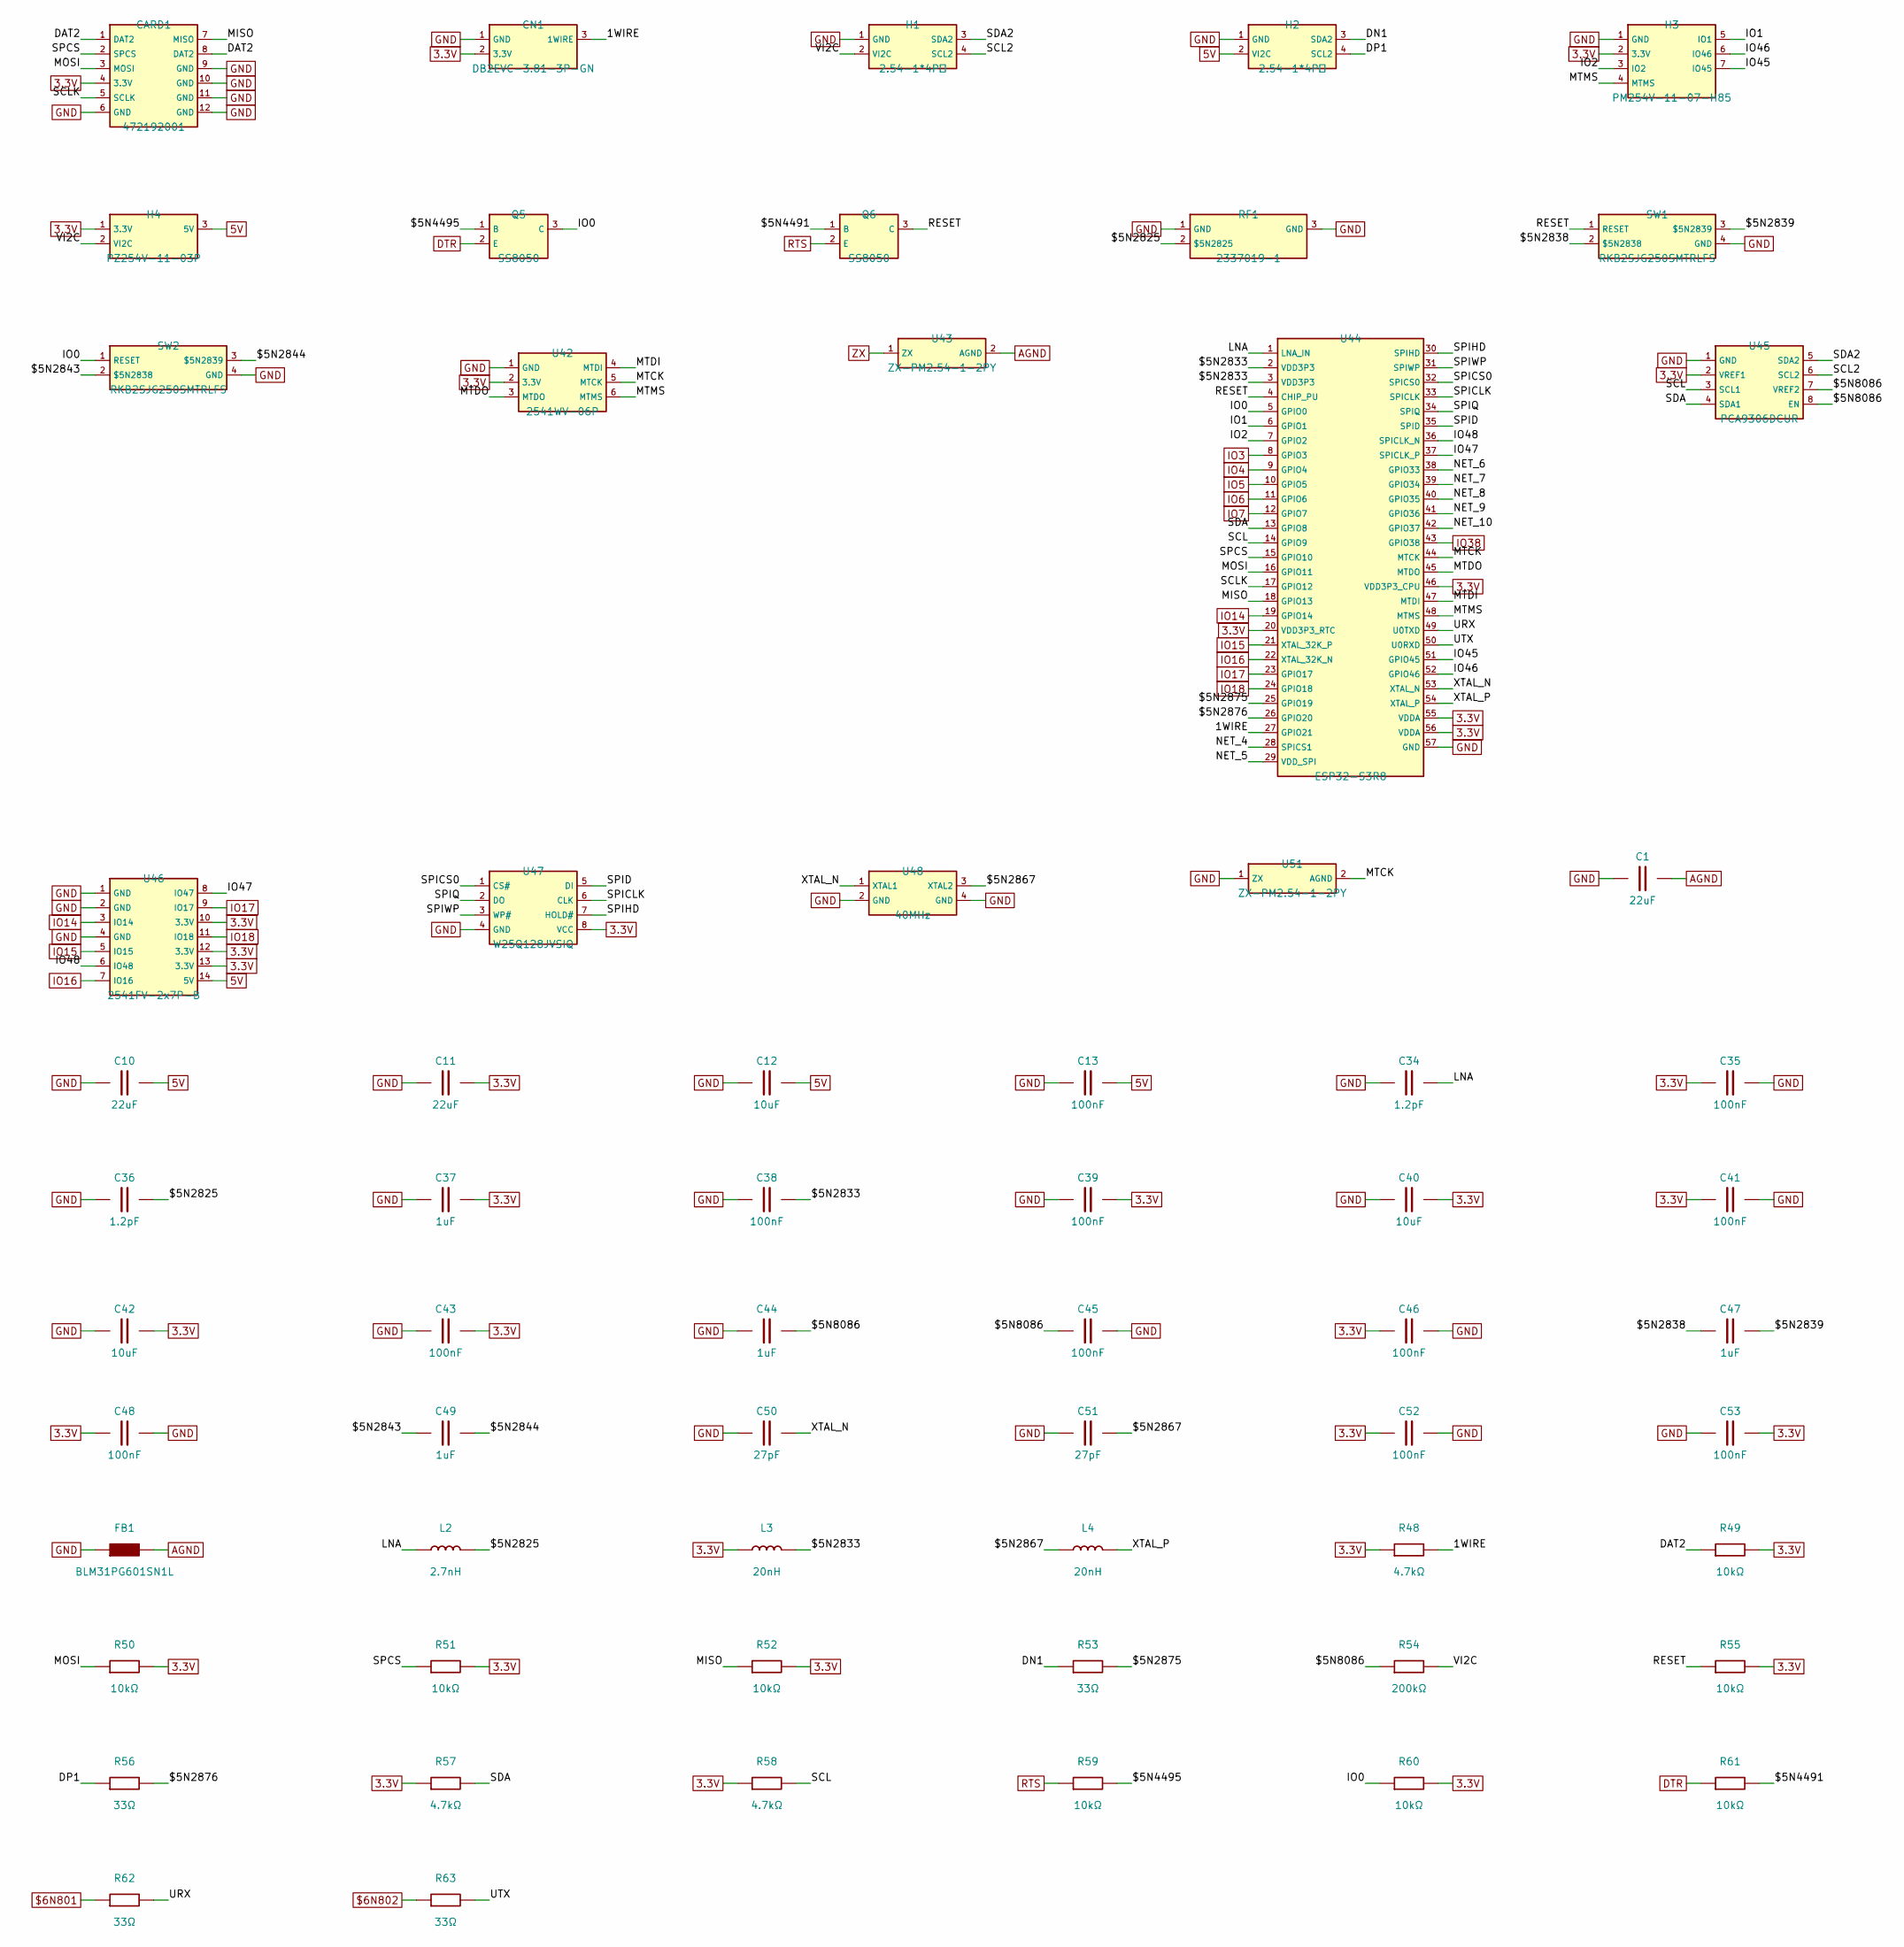
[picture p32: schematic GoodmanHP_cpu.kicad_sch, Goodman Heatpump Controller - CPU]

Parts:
C1: 22uF; C1812; LCSC C22388553
C10, C11: 22uF; C0805; LCSC C907991
C12, C40, C42: 10uF; C0402; LCSC C15525
C13, C35, C38, C39, C41, C43, C45, C46, C48, C52, C53: 100nF; C0201; LCSC C85923
C34, C36: 1.2pF; C0201; LCSC C85895
C37, C44, C47, C49: 1uF; C0201; LCSC C76929
C50, C51: 27pF; C0201; LCSC C384976
CARD1: 472192001; TF-SMD_472192001; LCSC C164170
CN1: DB2EVC-3.81-3P-GN; CONN-TH_3P-P3.81_DB2EVC-3.81-3P; LCSC C395692
FB1: BLM31PG601SN1L; L1206; LCSC C16902
H1, H2: 2.54-1*4P母; HDR-TH_4P-P2.54-V-F; LCSC C2718488
H3: PM254V-11-07-H85; HDR-TH_7P-P2.54-V-F; LCSC C2832270
H4: PZ254V-11-03P; HDR-TH_3P-P2.54-V-M_PZ254V-11-03P; LCSC C2937625
L2: 2.7nH; L0201; LCSC C7216765
L3, L4: 20nH; IND-SMD_L1.2-W0.6-1; LCSC C330860
Q5, Q6: SS8050; SOT-23-3_L2.9-W1.3-P1.90-LS2.4-BR; LCSC C916392
R48, R57, R58: 4.7kΩ; R0201; LCSC C138135
R49, R50, R51, R52, R55, R59, R60, R61: 10kΩ; R0201; LCSC C473048
R53, R56, R62, R63: 33Ω; R0201; LCSC C423356
R54: 200kΩ; R0201; LCSC C138163
RF1: 2337019-1; ANT-SMD_2337019-1; LCSC C434807
SW1, SW2: RKB2SJG250SMTRLFS; SW-SMD_4P-L4.2-W3.2-P2.15-LS4.6; LCSC C2927788
U42: 2541WV-06P; HDR-TH_6P-P2.54-V-M; LCSC C5383115
U43, U51: ZX-PM2.54-1-2PY; HDR-TH_2P-P2.54-V-F; LCSC C7499322
U44: ESP32-S3R8; QFN-56_L7.0-W7.0-P0.40-TL-EP4.0; LCSC C2913194
U45: PCA9306DCUR; SSOP-8_L2.0-W2.3-P0.50-LS3.1-BR; LCSC C33196
U46: 2541FV-2x7P-B; HDR-TH_2541FV-2X7P-B; LCSC C25503125
U47: W25Q128JVSIQ; SOIC-8_L5.3-W5.3-P1.27-LS8.0-BL; LCSC C113767
U48: 40MHz; CRYSTAL-SMD_4P-L2.0-W1.6-BL; LCSC C42464327

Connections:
1WIRE: CN1.3 (1WIRE), R48.2, U44.27 (GPIO21)
3.3V: C11.2, C35.1, C37.2, C39.2, C40.2, C41.1, C42.2, C43.2, C46.1, C48.1, C52.1, C53.2, CARD1.4 (3.3V), CN1.2 (3.3V), H3.2 (3.3V), H4.1 (3.3V), L3.1, R48.1, R49.2, R50.2, R51.2, R52.2, R55.2, R57.1, R58.1, R60.2, U42.2 (3.3V), U44.20 (VDD3P3_RTC), U44.46 (VDD3P3_CPU), U44.55 (VDDA), U44.56 (VDDA), U45.2 (VREF1), U46.10 (3.3V), U46.12 (3.3V), U46.13 (3.3V), U47.8 (VCC); also elsewhere on the board
5V: C10.2, C12.2, C13.2, H2.2 (VI2C), H4.3 (5V), U46.14 (5V); also elsewhere on the board
$5N2825: C36.2, L2.2, RF1.2 ($5N2825)
$5N2833: C38.2, L3.2, U44.2 (VDD3P3), U44.3 (VDD3P3)
$5N2838: C47.1, SW1.2 ($5N2838)
$5N2839: C47.2, SW1.3 ($5N2839)
$5N2843: C49.1, SW2.2 ($5N2838)
$5N2844: C49.2, SW2.3 ($5N2839)
$5N2867: C51.2, L4.1, U48.3 (XTAL2)
$5N2875: R53.2, U44.25 (GPIO19)
$5N2876: R56.2, U44.26 (GPIO20)
$5N4491: Q6.1 (B), R61.2
$5N4495: Q5.1 (B), R59.2
$5N8086: C44.2, C45.1, R54.1, U45.7 (VREF2), U45.8 (EN)
$6N801: R62.1; also elsewhere on the board
$6N802: R63.1; also elsewhere on the board
AGND: C1.2, FB1.2, U43.2 (AGND); also elsewhere on the board
DAT2: CARD1.1 (DAT2), CARD1.8 (DAT2), R49.1
DN1: H2.3 (SDA2), R53.1
DP1: H2.4 (SCL2), R56.1
DTR: Q5.2 (E), R61.1; also elsewhere on the board
GND: C1.1, C10.1, C11.1, C12.1, C13.1, C34.1, C35.2, C36.1, C37.1, C38.1, C39.1, C40.1, C41.2, C42.1, C43.1, C44.1, C45.2, C46.2, C48.2, C50.1, C51.1, C52.2, C53.1, CARD1.6 (GND), CARD1.9 (GND), CARD1.10 (GND), CARD1.11 (GND), CARD1.12 (GND), CN1.1 (GND), FB1.1, H1.1 (GND), H2.1 (GND), H3.1 (GND), RF1.1 (GND), RF1.3 (GND), SW1.4 (GND), SW2.4 (GND), U42.1 (GND), U44.57 (GND), U45.1 (GND), U46.1 (GND), U46.2 (GND), U46.4 (GND), U47.4 (GND), U48.2 (GND), U48.4 (GND), U51.1 (ZX); also elsewhere on the board
IO0: Q5.3 (C), R60.1, SW2.1 (RESET), U44.5 (GPIO0)
IO1: H3.5 (IO1), U44.6 (GPIO1)
IO2: H3.3 (IO2), U44.7 (GPIO2)
IO3: U44.8 (GPIO3); also elsewhere on the board
IO4: U44.9 (GPIO4); also elsewhere on the board
IO5: U44.10 (GPIO5); also elsewhere on the board
IO6: U44.11 (GPIO6); also elsewhere on the board
IO7: U44.12 (GPIO7); also elsewhere on the board
IO14: U44.19 (GPIO14), U46.3 (IO14); also elsewhere on the board
IO15: U44.21 (XTAL_32K_P), U46.5 (IO15); also elsewhere on the board
IO16: U44.22 (XTAL_32K_N), U46.7 (IO16); also elsewhere on the board
IO17: U44.23 (GPIO17), U46.9 (IO17); also elsewhere on the board
IO18: U44.24 (GPIO18), U46.11 (IO18); also elsewhere on the board
IO38: U44.43 (GPIO38); also elsewhere on the board
IO45: H3.7 (IO45), U44.51 (GPIO45)
IO46: H3.6 (IO46), U44.52 (GPIO46)
IO47: U44.37 (SPICLK_P), U46.8 (IO47)
IO48: U44.36 (SPICLK_N), U46.6 (IO48)
LNA: C34.2, L2.1, U44.1 (LNA_IN)
MISO: CARD1.7 (MISO), R52.1, U44.18 (GPIO13)
MOSI: CARD1.3 (MOSI), R50.1, U44.16 (GPIO11)
MTCK: U42.5 (MTCK), U44.44 (MTCK), U51.2 (AGND)
MTDI: U42.4 (MTDI), U44.47 (MTDI)
MTDO: U42.3 (MTDO), U44.45 (MTDO)
MTMS: H3.4 (MTMS), U42.6 (MTMS), U44.48 (MTMS)
NET_4: U44.28 (SPICS1)
NET_5: U44.29 (VDD_SPI)
NET_6: U44.38 (GPIO33)
NET_7: U44.39 (GPIO34)
NET_8: U44.40 (GPIO35)
NET_9: U44.41 (GPIO36)
NET_10: U44.42 (GPIO37)
RESET: Q6.3 (C), R55.1, SW1.1 (RESET), U44.4 (CHIP_PU)
RTS: Q6.2 (E), R59.1; also elsewhere on the board
SCL: R58.2, U44.14 (GPIO9), U45.3 (SCL1)
SCL2: H1.4 (SCL2), U45.6 (SCL2)
SCLK: CARD1.5 (SCLK), U44.17 (GPIO12)
SDA: R57.2, U44.13 (GPIO8), U45.4 (SDA1)
SDA2: H1.3 (SDA2), U45.5 (SDA2)
SPCS: CARD1.2 (SPCS), R51.1, U44.15 (GPIO10)
SPICLK: U44.33 (SPICLK), U47.6 (CLK)
SPICS0: U44.32 (SPICS0), U47.1 (CS#)
SPID: U44.35 (SPID), U47.5 (DI)
SPIHD: U44.30 (SPIHD), U47.7 (HOLD#)
SPIQ: U44.34 (SPIQ), U47.2 (DO)
SPIWP: U44.31 (SPIWP), U47.3 (WP#)
URX: R62.2, U44.49 (U0TXD)
UTX: R63.2, U44.50 (U0RXD)
VI2C: H1.2 (VI2C), H4.2 (VI2C), R54.2
XTAL_N: C50.2, U44.53 (XTAL_N), U48.1 (XTAL1)
XTAL_P: L4.2, U44.54 (XTAL_P)
ZX: U43.1 (ZX); also elsewhere on the board

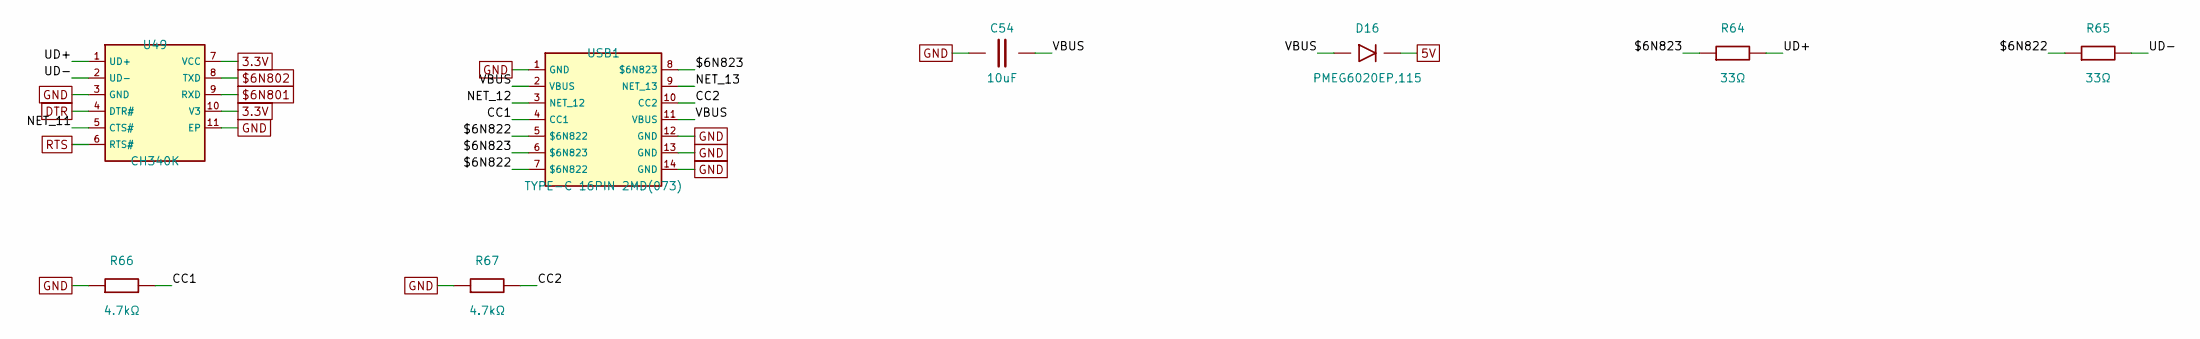
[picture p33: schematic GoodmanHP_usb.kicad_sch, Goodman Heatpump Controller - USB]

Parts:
C54: 10uF; C0402; LCSC C15525
D16: PMEG6020EP,115; SOD-128_L3.7-W2.5-LS4.7-FD; LCSC C179433
R64, R65: 33Ω; R0201; LCSC C423356
R66, R67: 4.7kΩ; R0201; LCSC C138135
U49: CH340K; ESOP-10_L4.9-W3.9-P1.00-LS6.2-BL-EP; LCSC C968586
USB1: TYPE-C 16PIN 2MD(073); USB-C-SMD_TYPE-C-6PIN-2MD-073; LCSC C2765186

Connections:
3.3V: U49.7 (VCC), U49.10 (V3); also elsewhere on the board
5V: D16.1 (K); also elsewhere on the board
$6N801: U49.9 (RXD); also elsewhere on the board
$6N802: U49.8 (TXD); also elsewhere on the board
$6N822: R65.1, USB1.5 ($6N822), USB1.7 ($6N822)
$6N823: R64.1, USB1.6 ($6N823), USB1.8 ($6N823)
CC1: R66.2, USB1.4 (CC1)
CC2: R67.2, USB1.10 (CC2)
DTR: U49.4 (DTR#); also elsewhere on the board
GND: C54.1, R66.1, R67.1, U49.3 (GND), U49.11 (EP), USB1.1 (GND), USB1.12 (GND), USB1.13 (GND), USB1.14 (GND); also elsewhere on the board
NET_11: U49.5 (CTS#)
NET_12: USB1.3 (NET_12)
NET_13: USB1.9 (NET_13)
RTS: U49.6 (RTS#); also elsewhere on the board
UD+: R64.2, U49.1 (UD+)
UD-: R65.2, U49.2 (UD-)
VBUS: C54.2, D16.2 (A), USB1.2 (VBUS), USB1.11 (VBUS)

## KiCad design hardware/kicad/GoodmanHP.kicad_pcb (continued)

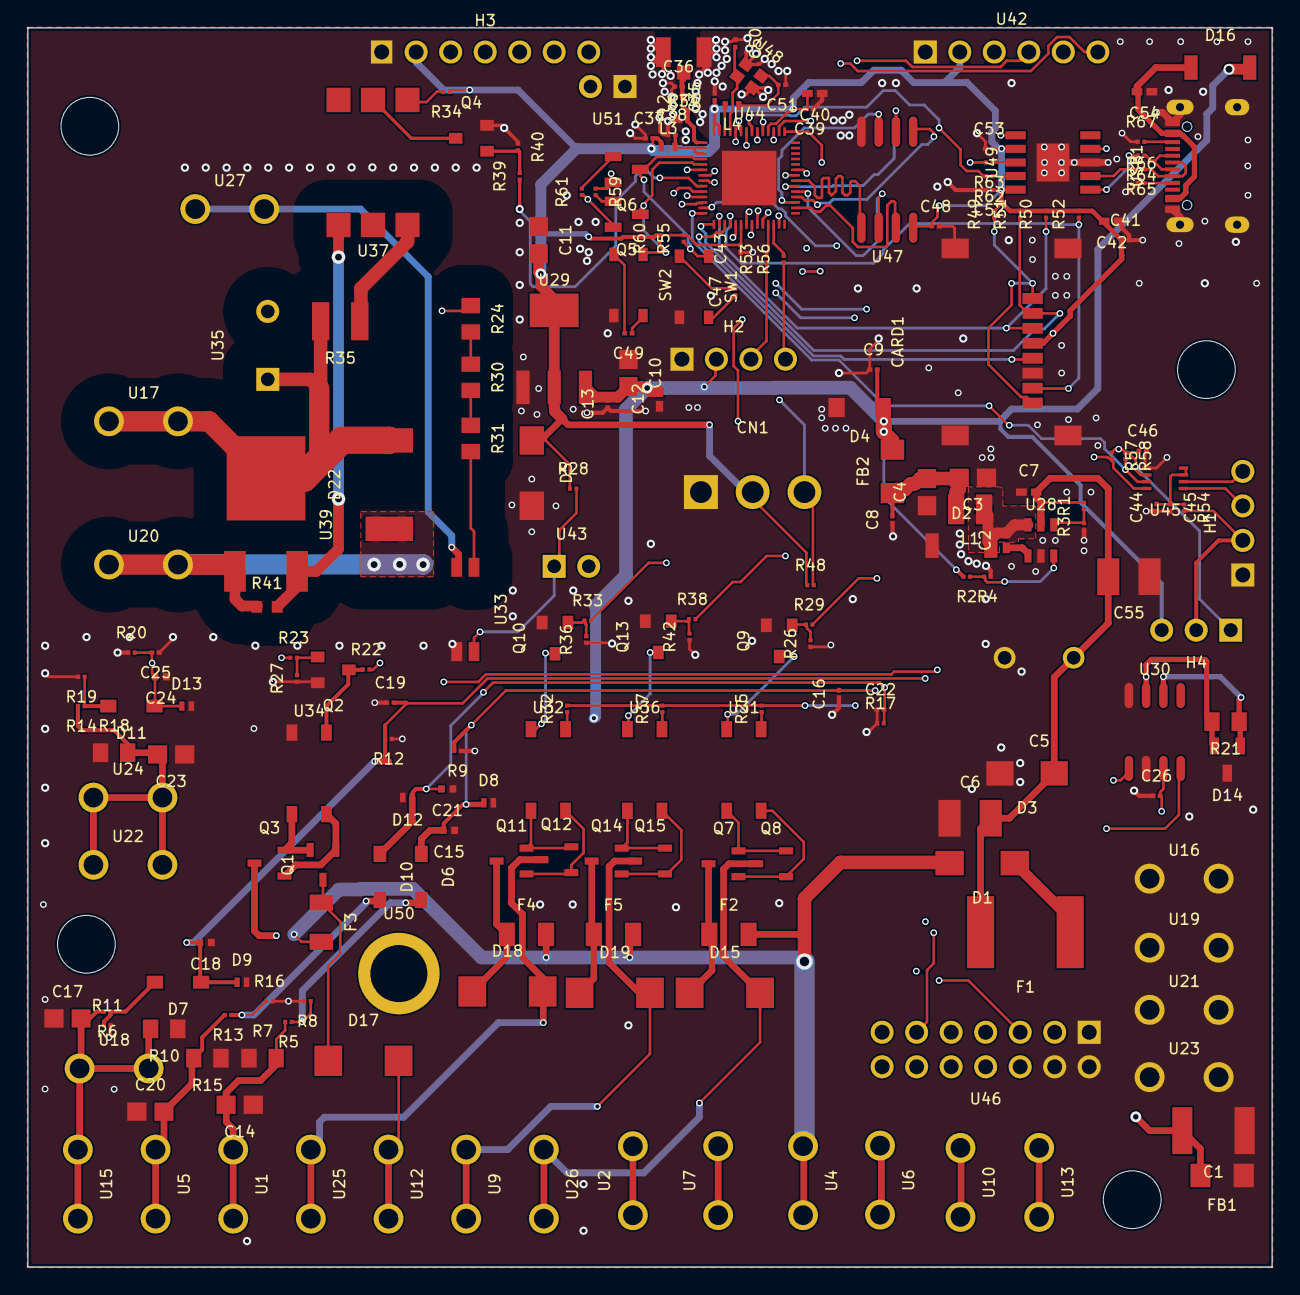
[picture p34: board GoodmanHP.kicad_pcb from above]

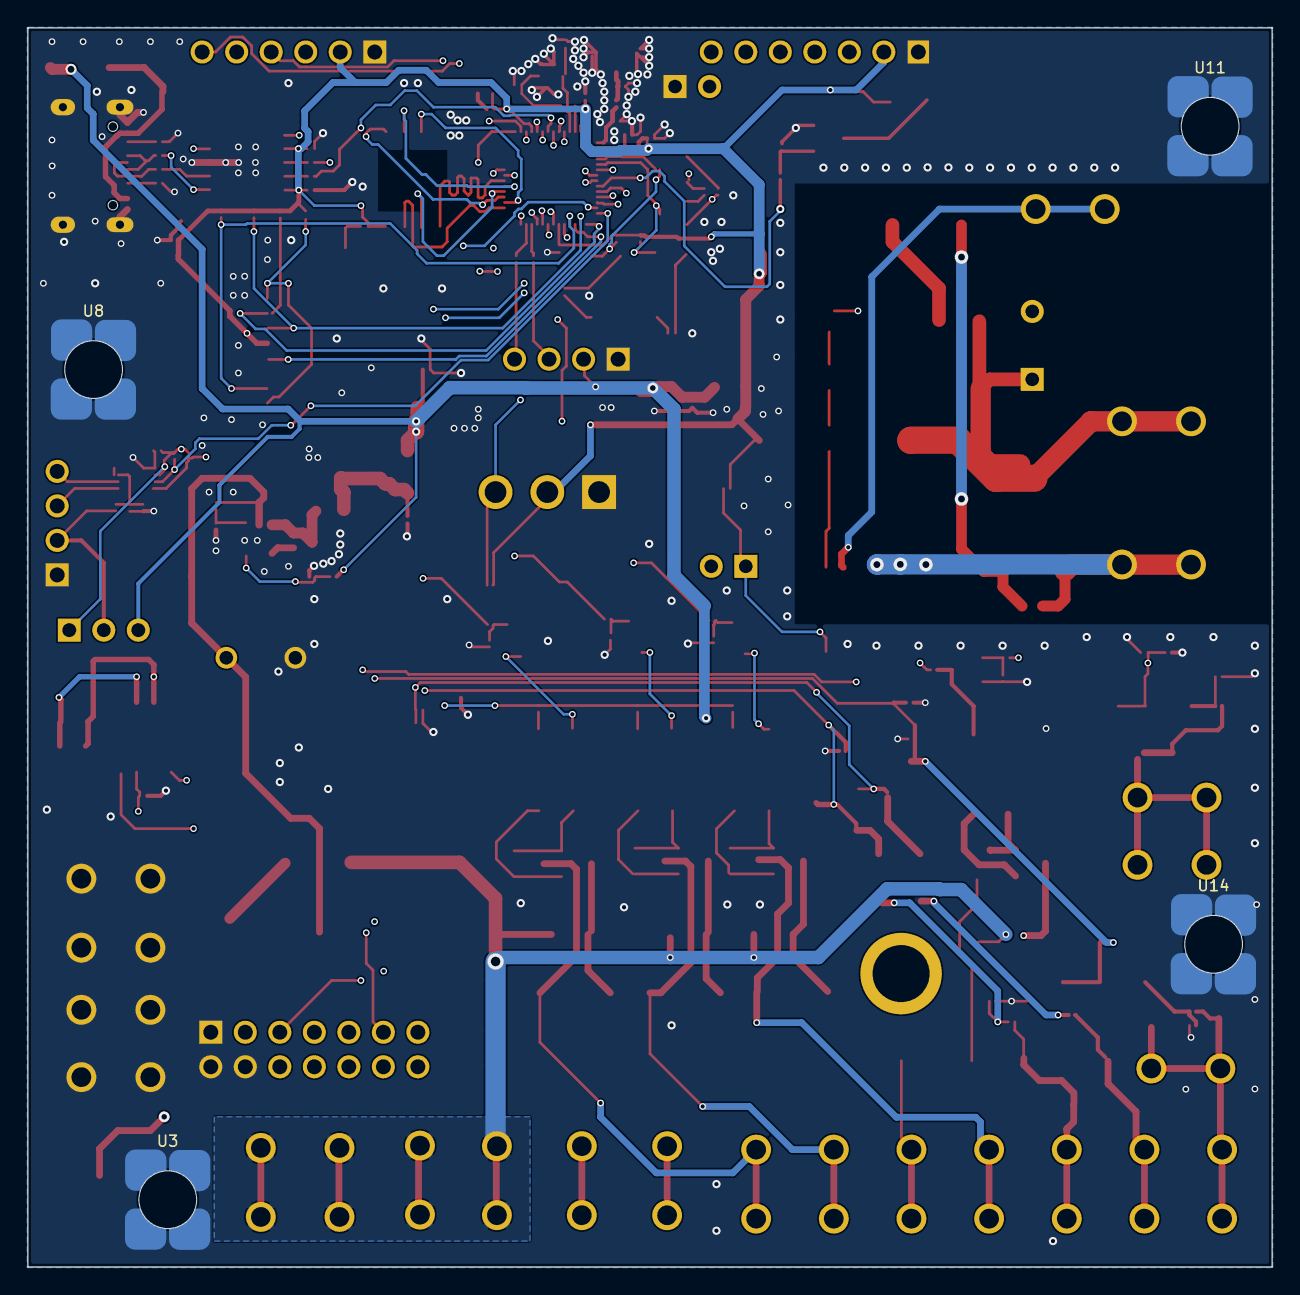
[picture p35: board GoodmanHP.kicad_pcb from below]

Board: 6 copper layers, 91.6 x 91.2 mm, 220 parts (4 on the bottom side), 132 nets.

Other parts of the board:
MH1, MH2, MH3, MH4, MH5, MH6: (no value)

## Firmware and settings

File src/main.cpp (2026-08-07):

#include <Arduino.h>
#include <esp_freertos_hooks.h>
#include <ArxContainer.h>
#include <OneWire.h>
#include <WiFiServer.h>
#include <DallasTemperature.h>
#include <SPI.h>
#include <Wire.h>
#include <SD.h>
#include <LittleFS.h>
#include <SimpleFTPServer.h>
#include <StringStream.h>
#include <TaskSchedulerDeclarations.h>
#include "CircularBuffer.hpp"
#include "Logger.h"
#include "OutPin.h"
#include "InputPin.h"
#include "GoodmanHP.h"
#include "Config.h"
#include "WebHandler.h"
#include "MQTTHandler.h"
#include "TempHistory.h"
#include "DisplayManager.h"
#include "OtaUtils.h"
#include "SPICurrentADC.h"
#include <HTTPClient.h>
#include "CANBus.h"

extern const char compile_date[] = __DATE__ " " __TIME__;
IPAddress _MQTT_HOST_DEFAULT = IPAddress(192, 168, 0, 46);
const char* _filename = "/config.txt";
const float MB_MULTIPLIER = 1.0/(1024.0*1024.0);
const u_int16_t n_elements = 2000;


#if CIRCULAR_BUFFER_INT_SAFE
#else
#error "Needs to set CIRCULAR_BUFFER_INT_SAFE"
#endif

u_int16_t _MQTT_PORT = 1883;
String _MQTT_USER = "debian";
String _MQTT_PASSWORD = "";

String _WIFI_SSID = "";
String _WIFI_PASSWORD = "";




#if defined (ARDUINO_ARCH_AVR)
#include <MemoryFree.h>
#elif defined(__arm__)
extern "C" char* sbrk(int incr);
static int freeMemory() {
  char top = 't';
  return &top - reinterpret_cast<char*>(sbrk(0));
}
#elif defined (ARDUINO_ARCH_ESP8266) || defined (ARDUINO_ARCH_ESP32)
int freeMemory() { return ESP.getFreeHeap();}
#else
//  Supply your own freeMemory method
int freeMemory() { return 0;}
#endif

//#define _TASK_MICRO_RES

// Config instance for SD card and configuration management
Config config;

FtpServer ftpSrv;
bool ftpActive = false;
unsigned long ftpStopTime = 0;
static String _ftpActivePassword;  // Must persist — SimpleFTPServer stores pointer, not copy


std::map<String, InputPin*> _isrEvent;

// Scheduler
Scheduler ts, hts;
u_int32_t _nextIdlePrintTime = 0;

u_int32_t _idleLoopCount = 0;
u_int32_t _workLoopCount = 0;
volatile bool InISR, InitialPinStateSet, FinalPinSetState;

// CPU load monitoring
// Core 0 (WiFi/system tasks, not app-controlled): FreeRTOS idle-hook timing.
//   Tracks actual idle microseconds per second using esp_timer_get_time().
//   Consecutive idle hook calls < 200us apart = continuous idle time.
//   Gaps > 200us = preempted by higher-priority task (not counted as idle).
// Core 1 (Arduino loopTask, runs ts.execute()): direct busy-time
//   accounting. loop() must call vTaskDelay(1) every pass so core 0's
//   idle task (and its hook) gets a chance to run; that forced delay
//   makes loopTask look idle almost 100% of the time, so an idle-hook
//   reading taken on core 1 itself is swamped by the delay rather than
//   reflecting real work. Instead we timestamp the actual work done each
//   pass and sum it directly. Note this measures wall-clock time the work
//   block took, not pure CPU cycles — AsyncTCP runs at priority 10 (vs.
//   loopTask's priority 1) and isn't pinned to a core, so if it preempts
//   loopTask mid-pass to service network I/O, that time is included too.
//   _loopIterCount (iterations/sec, see getLoopItersPerSec()) helps tell
//   "genuinely busy" apart from "frequently preempted".
static volatile int64_t _lastIdleCore0 = 0;
static volatile uint32_t _idleUsCore0 = 0;
static volatile uint32_t _busyUsCore1 = 0;
static volatile uint32_t _loopIterCount = 0;
static uint8_t _cpuLoadCore0 = 0;
static uint8_t _cpuLoadCore1 = 0;
static uint32_t _loopItersPerSec = 0;

static bool idleHookCore0() {
  int64_t now = esp_timer_get_time();
  int64_t delta = now - _lastIdleCore0;
  _lastIdleCore0 = now;
  if (delta > 0 && delta < 200) _idleUsCore0 += (uint32_t)delta;
  return false;
}

uint8_t getCpuLoadCore0() { return _cpuLoadCore0; }
uint8_t getCpuLoadCore1() { return _cpuLoadCore1; }
uint32_t getLoopItersPerSec() { return _loopItersPerSec; }

u_int32_t _wifiStartMillis = 0;

// WiFi AP fallback mode
static uint32_t _wifiDisconnectCount = 0;
bool _apModeActive = false;
String _apPassword;

// Rapid reboot detection — RTC memory survives software resets
RTC_NOINIT_ATTR static uint32_t _rapidRebootCount;
static const uint32_t RAPID_REBOOT_THRESHOLD = 3;
static const uint32_t REBOOT_STABLE_MS = 5UL * 60 * 1000; // 5 min
static bool _rebootRateLimited = false;

// Boot watchdog — crash detection via RTC memory
RTC_NOINIT_ATTR static uint32_t _crashBootCount;
static const uint32_t CRASH_BOOT_THRESHOLD = 3;
static const uint32_t BOOT_STABLE_MS = 30UL * 1000; // 30s
bool _safeMode = false;

u_long runTimeStart;
u_long currentRuntime;  

// put function declarations here:
#if defined (BOARD_ESP32_S3_WROOM)
const u_int8_t _lpsPin = GPIO_NUM_15;
const u_int8_t _dftPin = GPIO_NUM_16;
const u_int8_t _yPin = GPIO_NUM_17;
const u_int8_t _oPin = GPIO_NUM_18;
const u_int8_t _fanPin = GPIO_NUM_4;
const u_int8_t _CNTPin = GPIO_NUM_5;
const u_int8_t _WPin = GPIO_NUM_6;
const u_int8_t _RVPin = GPIO_NUM_7;
const u_int8_t _auxPin = GPIO_NUM_3;
const u_int8_t _sdaPin = GPIO_NUM_8;
const u_int8_t _sclPin = GPIO_NUM_9;
#elif  defined (BOARD_ESP32_ROVER)
const u_int8_t _dftPin = GPIO_NUM_16;
const u_int8_t _yPin = GPIO_NUM_17;
const u_int8_t _oPin = GPIO_NUM_18;
#else
#error "BUILD_ENV_NAME NOT RECOGNIZED"
#endif
const u_int8_t ONE_WIRE_BUS = GPIO_NUM_21;

// CAN bus
static const gpio_num_t PIN_CAN_TX = GPIO_NUM_38;
static const gpio_num_t PIN_CAN_RX = GPIO_NUM_14;
CANBus canBus(&ts, PIN_CAN_TX, PIN_CAN_RX);

// ProjectInfo is defined in Config.h

void tempSensorUpdateCallback(TempSensor *sensor);
void tempSensorChangeCallback(TempSensor *sensor);


void onInput(InputPin *pin);
bool onOutpin(OutPin *pin, bool on, bool inCallback, float &newPercent, float origPercent);

// Setup a oneWire instance to communicate with any OneWire devices (not just Maxim/Dallas temperature ICs)
std::map<String, InputPin* > activePins;

// GoodmanHP controller instance - contains input and output pin maps
GoodmanHP hpController(&ts);
WebHandler webHandler(80, &ts, &hpController);
MQTTHandler mqttHandler(&ts);
TempHistory tempHistory;
DisplayManager displayMgr(&ts);

OneWire oneWire(ONE_WIRE_BUS);

// Pass our oneWire reference to Dallas Temperature.
DallasTemperature sensors(&oneWire);

// ADS131M04 4-channel simultaneous-sampling SPI ADC for CT clamp current
// sensing (AIN0=compressor, AIN1=fan, AIN3=crankcase) + zero-cross line
// frequency reference (AIN2/ZX). Pins confirmed off the schematic and
// proven live via bringup/ads131m04/main.cpp -- see
// docs/ads131m04-current-sensor-design.md "Main-board interconnect".
// GPIO39 (RESET#/SYNC#) is a hand-soldered bodge wire onto the main board's
// JTAG debug header (MTCK), not a proper H3 connector pin -- H3 is a fixed
// 7-position part on the already-fabricated board with no 8th conductor
// available. See "RESET# bodge wire" / "Next PCB revision requirements" in
// the design doc.
static const SPICurrentADC::Pins SPI_ADC_PINS = {
  /*din*/   2,
  /*dout*/  42,
  /*sclk*/  1,
  /*cs*/    45,
  /*drdy*/  46,
  /*reset*/ 39,
};
// Constructed with the compile-time default OSR -- proj (which may carry a
// different OSR loaded from SD card config) isn't initialized yet at this
// point in static init order. setup() calls spiCurrentAdc.setOsr(proj.adcOsr)
// after config load and before begin() to apply the real configured value.
SPICurrentADC spiCurrentAdc(SPI_ADC_PINS);
bool spiAdcReady = false;


typedef enum AC_STATE { OFF, COOL, HEAT, DEFROST, ERROR, LOW_TEMP } ACState;
static String AC_STATE_STR[] = {"OFF", "COOL", "HEAT", "DEFROST", "ERROR", "LOW_TEMP"};
static String BOOL_STR[] = {"TRUE", "FALSE"};

ProjectInfo proj = {
  "Goodman Heatpump Control",
  compile_date,
  "Control Goodman heatpump including defrost mode.",
  "",
  false,
  50 * 1024 * 1024,  // maxLogSize: 50MB default
  10,                 // maxOldLogCount: 10 files default
  0,                  // heatRuntimeAccumulatedMs: restored from config
  "CST6CDT,M3.2.0,M11.1.0",  // timezone: US Central with auto DST
  20.0f,              // lowTempThreshold: 20°F default
  true,               // lowTempEnableW: W relay on in LOW_TEMP
  true,               // lowTempEnableAux: AUX signal participates in LOW_TEMP handling (turned OFF while below threshold)
  140.0f,             // highSuctionTempThreshold: 140°F default
  false,              // rvFail: not latched
  30000,              // rvShortCycleMs: 30s default
  30000,              // cntShortCycleMs: 30s default
  70.0f,              // highAmbientHeatLockoutF: 70°F default
  // Adaptive defrost bands
  23.0f,              // defrostColdMaxTempF: Cold ≤ 23°F
  31.0f,              // defrostWarmMinTempF: Warm ≥ 31°F
  1800000,            // defrostColdRuntimeMs: Cold 30 min
  120000,             // defrostColdMinRuntimeMs: Cold 2 min
  50.0f,              // defrostColdExitTempF: Cold 50°F
  3600000,            // defrostMidRuntimeMs: Mid 60 min
  90000,              // defrostMidMinRuntimeMs: Mid 1.5 min
  55.0f,              // defrostMidExitTempF: Mid 55°F
  5400000,            // defrostWarmRuntimeMs: Warm 90 min
  60000,              // defrostWarmMinRuntimeMs: Warm 1 min
  60.0f,              // defrostWarmExitTempF: Warm 60°F
  false,              // softwareDefrost: not active
  30000,              // stateValidationMs: 30s default
  2000,               // inputDelayMs: 2s default
  600,                // apFallbackSeconds: 10 minutes
  "",                 // apPassword: empty = auto-generate
  "",                 // ftpPassword: empty = default "admin"
  120,                // tempHistoryIntervalSec: 2 minutes default
  "dark",             // theme: dark default
  10,                 // displayPageIntervalSec: 10s default
  true,               // displayEnabled: on by default
  false,              // forceSafeMode: not forced
  "Goodman HP",       // systemName: default system name
  "goodman",          // mqttPrefix: default MQTT topic prefix
  0,                  // sessionTimeoutMinutes: disabled by default
  2,                  // pollIntervalSec: 2 second default
  // Current monitoring (ADS131M04 CT clamp, SPI, simultaneous 4-channel)
  0.0f,               // compressorOvercurrentAmps: disabled
  0.0f,               // fanOvercurrentAmps: disabled
  5000,               // overcurrentDelayMs: 5s default
  0.0f,               // lockedRotorThreshold: disabled
  5000,               // lockedRotorTimeoutMs: 5s default
  false,              // lockedRotorFault: not latched
  30.0f,              // compressorCtRatio: SCT-013-030
  30.0f,              // fanCtRatio: SCT-013-030
  5.0f,               // crankcaseCtRatio: SCT-013-005
  0.0f,               // crankcaseExpectedAmps: not monitored
  0.0f,               // compressorBurdenOhms: voltage-output CT (no burden)
  0.0f,               // fanBurdenOhms: voltage-output CT (no burden)
  0.0f,               // crankcaseBurdenOhms: voltage-output CT (no burden)
  3,                  // adcOsr: 1024/4kSPS default
  // Weather ambient temperature fallback
  "none",              // weatherSource
  "",                  // weatherMqttTopic
  "",                  // weatherApiKey
  "",                  // weatherZipCode
  "US",                // weatherCountry
  30,                  // weatherStaleMinutes
  10,                  // weatherRefreshMinutes
  0.0f,                // internalTempOffsetF
  // HP unit info
  3.0f,                // hpTonnage: 3 ton default
  true,                // scrollCompressor: scroll type default
  // CAN bus
  false                // canEnabled: off by default
};


ACState _acState = OFF;
bool OnReadInputsEnable();
void OnReadInputsDisable();
bool OnInputChangeEnable();
void OnInputChangeDisable();
void OnRunTimeUpdate();
void getTempSensors();
void getTempSensors(TempSensorMap& tempMap);
bool onWifiWaitEnable();
void onWifiWaitDisable();
bool CheckTickTime(InputPin *pin);
void onCheckInputQueue();

void onInput(InputPin *pin){
  Log.info("InputPin", "Name: %s Value: %d", pin->getName(), pin->getValue());
}

bool onOutpin(OutPin *pin, bool on, bool inCallback, float &newPercent, float origPercent){
  //cout << "Output pin:" << pin->getName() << " On:" << pin->isPinOn() << endl; 
  Log.info("OutPin", "Name: %s State: %d Requested State: %d New Percent On: %lf Orig Percent On: %lf", pin->getName(), pin->isPinOn(), on, newPercent, origPercent);
  return true;
}

Task tWaitOnWiFi(TASK_SECOND, 60, [](){
  Serial.print(".");
}, &ts, false, onWifiWaitEnable, onWifiWaitDisable);


Task tRuntime(TASK_MINUTE, TASK_FOREVER, &OnRunTimeUpdate, &ts, false);

Task _tGetInputs(500 * TASK_MILLISECOND, TASK_FOREVER, &onCheckInputQueue, &ts, false);

// Save heat runtime to SD card every 5 minutes
void onSaveRuntime();
Task tSaveRuntime(5 * TASK_MINUTE, TASK_FOREVER, &onSaveRuntime, &ts, false);

// Log temperature history to per-sensor CSV files every 30 seconds
void onLogTempsCSV();
void cleanOldTempFiles(int maxAgeDays);
Task tLogTempsCSV(2 * TASK_MINUTE, TASK_FOREVER, &onLogTempsCSV, &ts, false);
static char _tempsCsvDate[12] = "";

// CPU load calculation every 1 second
void onCalcCpuLoad();
Task tCpuLoad(TASK_SECOND, TASK_FOREVER, &onCalcCpuLoad, &ts, false);

// Clear crash boot counter after 30s stable uptime (boot watchdog)
Task tBootStable(BOOT_STABLE_MS, TASK_ONCE, []() {
    _crashBootCount = 0;
    Log.info("MAIN", "Boot stable (30s), crash counter reset to 0");
}, &ts, true);  // enabled immediately on boot

// Clear rapid reboot counter after 5 min stable uptime (DoS protection)
Task tRebootStable(REBOOT_STABLE_MS, TASK_ONCE, []() {
    _rapidRebootCount = 0;
    _rebootRateLimited = false;
    Log.info("MAIN", "Stable uptime (5 min), reboot rate limit cleared");
}, &ts, true);  // enabled immediately on boot

// Backfill temp history from SD after NTP sync
void onBackfillTempHistory();
Task tBackfillTempHistory(5 * TASK_SECOND, 12, &onBackfillTempHistory, &ts, false); // retry every 5s up to 12 times (60s)

// CAN bus publish task — sends state and temps every 2 seconds
void onCanPublish();
void onCanReceive(uint32_t id, const uint8_t* data, uint8_t len);
Task tCanPublish(2 * TASK_SECOND, TASK_FOREVER, &onCanPublish, &ts, false);



/**
 * NOTE: ISR logic should be kept simple for both timings and prevent strange core panics.
 * Love this ESP32 ISR as it supports arguments. This allowed me to pass a pointer to
 * ISR function with my input pin structure to help track pin state. 
 */
void IRAM_ATTR inputISRChange(void *arg) {
  InputPin* pinInfo = static_cast<InputPin*>(arg);
  if(pinInfo == nullptr) {
    InISR = false;
    return;
  }
  pinInfo->setPrevValue();
  pinInfo->changedNow();
  if( _isrEvent.find(pinInfo->getName()) == _isrEvent.end())
  {
    _isrEvent[pinInfo->getName()] = pinInfo;
  }
}
bool CheckTickTime(InputPin *pin){
  uint32_t curTime = millis();
  if(pin == nullptr) return false;
  if(curTime >= pin->changedAtTick() + 50 || pin->getPreValue() != pin->getValue()){
    return true;
  }
  else
  { 
    return false;
  }
}

bool onWifiWaitEnable(){
  if(WiFi.isConnected()){
    return false;
  }
  mqttHandler.disconnect();
  return true;
}

// Weather ambient temperature fetch via HTTP (OpenWeatherMap)
void onFetchWeather();
Task tFetchWeather(10 * TASK_MINUTE, TASK_FOREVER, &onFetchWeather, &ts, false);

// Ambient failover test — auto-cancel after 30 minutes
void onFailoverTestEnd();
Task tFailoverTestEnd(30 * TASK_MINUTE, 1, &onFailoverTestEnd, &ts, false);

// Forward declaration for AP reconnect task
void onAPReconnect();
Task tAPReconnect(TASK_MINUTE, TASK_FOREVER, &onAPReconnect, &ts, false);

void startAPMode() {
  String apSSID = proj.systemName.length() > 0 ? proj.systemName : "Goodman HP";

  // Password: configured > previously generated > new random
  if (proj.apPassword.length() >= 8) {
    _apPassword = proj.apPassword;
  } else if (_apPassword.length() == 0) {
    _apPassword = Config::generateRandomPassword();
  }
  // else: reuse existing _apPassword

  if (!_apModeActive) {
    WiFi.disconnect(true);
    WiFi.mode(WIFI_AP_STA);
    WiFi.softAP(apSSID.c_str(), _apPassword.c_str());
    _apModeActive = true;
  }

  IPAddress apIP = WiFi.softAPIP();
  Log.warn("WiFi", "========================================");
  Log.warn("WiFi", "AP MODE ACTIVE");
  Log.warn("WiFi", "SSID: %s", apSSID.c_str());
  Log.warn("WiFi", "Password: %s", _apPassword.c_str());
  Log.warn("WiFi", "IP: %s", apIP.toString().c_str());
  Log.warn("WiFi", "========================================");
  Serial.println();
  Serial.println("*** AP MODE ***");
  Serial.printf("SSID: %s\n", apSSID.c_str());
  Serial.printf("Pass: %s\n", _apPassword.c_str());
  Serial.printf("IP:   %s\n", apIP.toString().c_str());
  Serial.println("***************");

  // Start periodic WiFi reconnect attempts using AP fallback interval
  tAPReconnect.setInterval(proj.apFallbackSeconds * (unsigned long)TASK_SECOND);
  tAPReconnect.enableDelayed();

  // Kick off STA connection attempt in background
  if (_WIFI_SSID.length() > 0) {
    WiFi.begin(_WIFI_SSID.c_str(), _WIFI_PASSWORD.c_str());
  }
}

String startAPModeTest() {
  String apSSID = proj.systemName.length() > 0 ? proj.systemName : "Goodman HP";
  // Password: configured > previously generated > new random
  if (proj.apPassword.length() >= 8) {
    _apPassword = proj.apPassword;
  } else if (_apPassword.length() == 0) {
    _apPassword = Config::generateRandomPassword();
  }
  // Keep existing WiFi — add AP alongside (AP_STA)
  WiFi.mode(WIFI_AP_STA);
  WiFi.softAP(apSSID.c_str(), _apPassword.c_str());
  _apModeActive = true;
  Log.info("WiFi", "AP test mode started - SSID: %s Pass: %s IP: %s",
           apSSID.c_str(), _apPassword.c_str(), WiFi.softAPIP().toString().c_str());
  // Auto-exit after fallback interval when WiFi is still connected
  tAPReconnect.setInterval(proj.apFallbackSeconds * (unsigned long)TASK_SECOND);
  tAPReconnect.enableDelayed();
  return _apPassword;
}

void stopAPMode() {
  _apModeActive = false;
  // Keep _apPassword for reuse
  tAPReconnect.disable();
  WiFi.softAPdisconnect(true);
  WiFi.mode(WIFI_STA);
  Log.info("WiFi", "AP mode stopped");
  _wifiDisconnectCount = 0;
  if (_WIFI_SSID.length() > 0) {
    WiFi.begin(_WIFI_SSID.c_str(), _WIFI_PASSWORD.c_str());
  }
}

void onAPReconnect() {
  if (!_apModeActive) {
    tAPReconnect.disable();
    return;
  }

  if (WiFi.isConnected()) {
    // WiFi reconnected — exit AP mode gracefully
    Log.info("WiFi", "WiFi reconnected to %s, exiting AP mode", _WIFI_SSID.c_str());
    _apModeActive = false;
    _wifiDisconnectCount = 0;
    tAPReconnect.disable();
    WiFi.softAPdisconnect(true);
    WiFi.mode(WIFI_STA);
    mqttHandler.startReconnect();
    return;
  }

  // Not connected — retry
  if (_WIFI_SSID.length() > 0) {
    Log.info("WiFi", "AP mode: retrying WiFi connection to %s", _WIFI_SSID.c_str());
    WiFi.begin(_WIFI_SSID.c_str(), _WIFI_PASSWORD.c_str());
  }
}

void onWifiWaitDisable(){
  Serial.println();
  if (WiFi.isConnected()) {
    _wifiDisconnectCount = 0;
    Log.info("WiFi", "IP: %s", WiFi.localIP().toString().c_str());
  } else {
    _wifiDisconnectCount += 60;
    Log.warn("WiFi", "Connection timed out (%lu/%lu sec), no IP assigned",
             _wifiDisconnectCount, proj.apFallbackSeconds);
    if (_wifiDisconnectCount >= proj.apFallbackSeconds) {
      startAPMode();
      return;
    }
  }
  mqttHandler.startReconnect();
}

void printAddress(DeviceAddress temp);

void wifiConnected(){
  Serial.printf("WiFi Connected within %lu ms.\n", millis() - _wifiStartMillis);
  mqttHandler.startReconnect();
}

void onWiFiEvent(arduino_event_id_t event, arduino_event_info_t info){
  switch(event){
    case SYSTEM_EVENT_STA_GOT_IP:
      _wifiDisconnectCount = 0;
      tWaitOnWiFi.disable();
      webHandler.startNtpSync();
      Log.info("WIFI", "Got ip: %s", webHandler.getWiFiIP());
      // Trigger immediate weather fetch on WiFi connect
      if (tFetchWeather.isEnabled()) tFetchWeather.forceNextIteration();
      if (_apModeActive) {
        Log.info("WiFi", "WiFi reconnected while in AP mode, exiting AP");
        _apModeActive = false;
        tAPReconnect.disable();
        WiFi.softAPdisconnect(true);
        WiFi.mode(WIFI_STA);
      }
      break;
    case SYSTEM_EVENT_STA_DISCONNECTED:
      if (_apModeActive) break;
      _wifiStartMillis = millis();
      tWaitOnWiFi.enableDelayed();
      mqttHandler.stopReconnect();
      Log.warn("WIFI", "WiFi lost connection");
      break;
    case SYSTEM_EVENT_STA_CONNECTED:
      wifiConnected();
      break;
  }
} 

void connectToWifi() {
  WiFi.begin(_WIFI_SSID, _WIFI_PASSWORD);
}
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
void loop() {
  if (webHandler.shouldReboot()) {
    Serial.println("Rebooting...");
    vTaskDelay(pdMS_TO_TICKS(100));
    ESP.restart();
  }

  _loopIterCount++;
  int64_t workStartUs = esp_timer_get_time();

  if (ftpActive && ftpStopTime > 0 && millis() >= ftpStopTime) {
    ftpSrv.end();
    ftpActive = false;
    ftpStopTime = 0;
    Log.info("FTP", "FTP auto-disabled (timeout)");
  }
  if (ftpActive) ftpSrv.handleFTP();

  bool bIdle = ts.execute();
  if (bIdle) {
    _idleLoopCount++;
    printIdleStatus();
  } else {
    _workLoopCount++;
  }

  // Drain queued ADS131M04 SPI ADC frames (pushed by the dedicated
  // DRDY-driven acquisition task) — must run every pass, not just once/sec,
  // so the consumer doesn't fall behind the ~4kHz sample stream.
  hpController.tickCurrentAcquisition();

  _busyUsCore1 += (uint32_t)(esp_timer_get_time() - workStartUs);
  vTaskDelay(1); // Yield to FreeRTOS so core 0's idle hook can fire
}

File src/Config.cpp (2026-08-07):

#include "Config.h"
#include "esp_hmac.h"
#include "esp_random.h"

// External callbacks for temp sensors
extern void tempSensorUpdateCallback(TempSensor* sensor);
extern void tempSensorChangeCallback(TempSensor* sensor);

uint8_t Config::_aesKey[32] = {0};
bool Config::_encryptionReady = false;
String Config::_obfuscationKey = "";

void Config::setObfuscationKey(const String& key) {
    _obfuscationKey = key;
}

Config::Config()
    : _sdInitialized(false)
    , _mqttHost(192, 168, 0, 46)
    , _mqttPort(1883)
    , _mqttUser("debian")
    , _mqttPassword("")
    , _wifiSSID("")
    , _wifiPassword("")
    , _adminPasswordHash("")
    , _tempDiscoveryCb(nullptr)
    , _proj(nullptr)
{
}

bool Config::initEncryption() {
    static const uint8_t salt[] = "GoodmanHP-Config-Encrypt-v1";
    esp_err_t err = esp_hmac_calculate(HMAC_KEY0, salt, sizeof(salt) - 1, _aesKey);
    _encryptionReady = (err == ESP_OK);
    return _encryptionReady;
}

String Config::encryptPassword(const String& plaintext) {
    if (plaintext.length() == 0) return plaintext;

    // Fall back to XOR obfuscation when eFuse HMAC key is not available
    if (!_encryptionReady) {
        if (_obfuscationKey.length() == 0) return plaintext;
        size_t len = plaintext.length();
        uint8_t* xored = new uint8_t[len];
        for (size_t i = 0; i < len; i++) {
            xored[i] = plaintext[i] ^ _obfuscationKey[i % _obfuscationKey.length()];
        }
        size_t outLen = 0;
        mbedtls_base64_encode(nullptr, 0, &outLen, xored, len);
        uint8_t* b64 = new uint8_t[outLen + 1];
        mbedtls_base64_encode(b64, outLen + 1, &outLen, xored, len);
        b64[outLen] = '\0';
        String result = "$ENC$" + String((char*)b64);
        delete[] xored;
        delete[] b64;
        return result;
    }

    // Generate 12-byte random IV
    uint8_t iv[12];
    esp_fill_random(iv, sizeof(iv));

    size_t ptLen = plaintext.length();
    uint8_t* ciphertext = new uint8_t[ptLen];
    uint8_t tag[16];

    mbedtls_gcm_context gcm;
    mbedtls_gcm_init(&gcm);
    mbedtls_gcm_setkey(&gcm, MBEDTLS_CIPHER_ID_AES, _aesKey, 256);
    mbedtls_gcm_crypt_and_tag(&gcm, MBEDTLS_GCM_ENCRYPT, ptLen,
        iv, sizeof(iv), nullptr, 0,
        (const uint8_t*)plaintext.c_str(), ciphertext, sizeof(tag), tag);
    mbedtls_gcm_free(&gcm);

    // Pack: IV[12] + ciphertext[N] + tag[16]
    size_t packedLen = 12 + ptLen + 16;
    uint8_t* packed = new uint8_t[packedLen];
    memcpy(packed, iv, 12);
    memcpy(packed + 12, ciphertext, ptLen);
    memcpy(packed + 12 + ptLen, tag, 16);
    delete[] ciphertext;

    // Base64 encode
    size_t b64Len = 0;
    mbedtls_base64_encode(nullptr, 0, &b64Len, packed, packedLen);
    uint8_t* b64 = new uint8_t[b64Len + 1];
    mbedtls_base64_encode(b64, b64Len + 1, &b64Len, packed, packedLen);
    b64[b64Len] = '\0';
    delete[] packed;

    String result = "$AES$" + String((char*)b64);
    delete[] b64;
    return result;
}

String Config::decryptPassword(const String& encrypted) {
    if (encrypted.startsWith("$AES$")) {
        if (!_encryptionReady) return "";

        String b64Part = encrypted.substring(5);
        size_t decodedLen = 0;
        mbedtls_base64_decode(nullptr, 0, &decodedLen,
            (const uint8_t*)b64Part.c_str(), b64Part.length());

        if (decodedLen < 12 + 16) return "";  // IV + tag minimum

        uint8_t* decoded = new uint8_t[decodedLen];
        mbedtls_base64_decode(decoded, decodedLen, &decodedLen,
            (const uint8_t*)b64Part.c_str(), b64Part.length());

        // Unpack: IV[12] + ciphertext[N] + tag[16]
        uint8_t* iv = decoded;
        size_t ctLen = decodedLen - 12 - 16;
        uint8_t* ciphertext = decoded + 12;
        uint8_t* tag = decoded + 12 + ctLen;

        uint8_t* plaintext = new uint8_t[ctLen + 1];

        mbedtls_gcm_context gcm;
        mbedtls_gcm_init(&gcm);
        mbedtls_gcm_setkey(&gcm, MBEDTLS_CIPHER_ID_AES, _aesKey, 256);
        int ret = mbedtls_gcm_auth_decrypt(&gcm, ctLen,
            iv, 12, nullptr, 0, tag, 16,
            ciphertext, plaintext);
        mbedtls_gcm_free(&gcm);
        delete[] decoded;

        if (ret != 0) {
            delete[] plaintext;
            return "";  // Auth failed — tampered or wrong key
        }

        plaintext[ctLen] = '\0';
        String result = String((char*)plaintext);
        delete[] plaintext;
        return result;
    }
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

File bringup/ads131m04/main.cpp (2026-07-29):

// ADS131M04 minimal SPI bring-up sketch.
//
// Purpose: confirm the daughter board is wired correctly and the ADC
// actually talks over SPI, before writing the real SPICurrentADC driver.
// Does two independent, unrelated checks:
//   1. RREG-read the ID and STATUS registers and print the raw response.
//   2. Watch DRDY# and report whether/how fast it's toggling.
// See docs/ads131m04-current-sensor-design.md for the full protocol
// writeup and pin mapping this is based on.
//
// Build/upload as its own PlatformIO environment, separate from the main
// firmware:
//   pio run -e ads131m04_bringup -t upload -t monitor

#include <Arduino.h>
#include <SPI.h>

// Pin mapping confirmed against the live schematic (H3 7-pin header), see
// "Main-board interconnect" in the design doc. Not shared with any other
// bus on this board.
static const int PIN_DIN  = 2;   // ESP32 MOSI -> ADC DIN
static const int PIN_DOUT = 42;  // ESP32 MISO <- ADC DOUT (also /MTMS; fine as GPIO, JTAG unused here)
static const int PIN_SCLK = 1;   // ESP32 SCK  -> ADC SCLK
static const int PIN_CS   = 45;  // ESP32 GPIO -> ADC CS# (active low, manual toggle)
static const int PIN_DRDY = 46;  // ADC DRDY# -> ESP32 GPIO (active low, push-pull, no pull-up needed)

// RESET#/SYNC# bodge wire (not on H3 -- H3 is a fixed 7-pin connector).
// GPIO39 is one of the 3 pins freed by tonight's MAX6675 removal. Wired
// open-drain: R3 (100k, on the daughter board) pulls this high/idle by
// default, this pin only ever drives it low to assert a reset. See
// "RESET# bodge wire" in the design doc.
static const int PIN_RESET = 39;

// Conservative bring-up clock. ADS131M04 supports much faster (see
// datasheet timing table); no reason to push it until basic comms work.
static const uint32_t SPI_HZ = 1000000;

// SPI mode 1: CPOL=0, CPHA=1 (confirmed against SBAS890D).
static SPISettings spiSettings(SPI_HZ, MSBFIRST, SPI_MODE1);

// Reset default word length is 24-bit; every "word" below is 3 bytes.
static const int WORD_BYTES = 3;

// A full frame at the reset default (4 channels enabled, CRC output
// disabled) is 6 words: command/response + CH0..CH3 + CRC. RREG/WREG
// responses land in word 1 of the *next* frame, not the one the command
// was sent in -- see "SPI protocol" in the design doc.
static const int FRAME_WORDS = 6;

// Command word builders (Table 8-11, SBAS890D).
static const uint16_t CMD_NULL = 0x0000;

static uint16_t cmdRREG(uint8_t addr, uint8_t count) {
    // 101a aaaa annn nnnn: opcode(3) | address(6) | (count-1)(7)
    return (0x5 << 13) | ((addr & 0x3F) << 7) | ((count - 1) & 0x7F);
}

// Clocks one full frame. word0 is the command/response word (DIN on the
// way out, previous command's response on the way back); the remaining
// FRAME_WORDS-1 words are clocked with DIN=0 (don't-care per the protocol)
// and their DOUT captured into resp[1..FRAME_WORDS-1].
static void spiFrame(uint16_t word0, uint32_t resp[FRAME_WORDS]) {
    digitalWrite(PIN_CS, LOW);
    SPI.beginTransaction(spiSettings);

    uint32_t out = (uint32_t)word0 << 8;  // 24-bit word, data left-justified
    uint32_t in = 0;
    for (int b = 0; b < WORD_BYTES; b++) {
        uint8_t txByte = (out >> (16 - 8 * b)) & 0xFF;
        uint8_t rxByte = SPI.transfer(txByte);
        in = (in << 8) | rxByte;
    }
    resp[0] = in;

    for (int w = 1; w < FRAME_WORDS; w++) {
        uint32_t wIn = 0;
        for (int b = 0; b < WORD_BYTES; b++) {
            uint8_t rxByte = SPI.transfer(0x00);
            wIn = (wIn << 8) | rxByte;
        }
        resp[w] = wIn;
    }

    SPI.endTransaction();
    digitalWrite(PIN_CS, HIGH);
    delayMicroseconds(2);  // CS high time between frames
}

// Read a single register: send RREG this frame, NULL the next frame, and
// the register value comes back as word0 of that second frame's response.
static uint32_t readRegister(uint8_t addr) {
    uint32_t resp[FRAME_WORDS];
    spiFrame(cmdRREG(addr, 1), resp);
    spiFrame(CMD_NULL, resp);
    return resp[0];
}

// Pulses RESET#/SYNC# low long enough to force a real device reset, not a
// SYNC pulse -- datasheet minimum is 2048 tCLKIN (~250us at 8.192MHz);
// 10ms gives 40x margin. Re-reads ID/STATUS afterward so a bodge-wire test
// can confirm the ADC actually came back.
static void forceReset() {
    Serial.println("Asserting RESET# low for 10ms...");
    digitalWrite(PIN_RESET, LOW);
    delay(10);
    digitalWrite(PIN_RESET, HIGH);  // open-drain release; R3 pulls it back up
    delay(10);  // tPOR-equivalent settling, same margin as cold boot

    uint32_t id = readRegister(0x00);
    uint32_t status = readRegister(0x01);
    Serial.printf("Post-reset ID register:     0x%06lX\n", (unsigned long)id);
    Serial.printf("Post-reset STATUS register: 0x%06lX\n", (unsigned long)status);
    Serial.println("Compare against the pre-reset values printed at boot --");
    Serial.println("should read the same reset-default STATUS, and DRDY#");
    Serial.println("toggling below should resume within a second or two.");
}

// ADC data is 24-bit two's complement, left-justified in the 24-bit word
// (same left-justified convention as commands -- see datasheet section
// referenced above). Sign-extend from bit 23 to get a real signed value.
static int32_t signExtend24(uint32_t raw) {
    if (raw & 0x800000) raw |= 0xFF000000;
    return (int32_t)raw;
}

static uint32_t drdyToggleCount = 0;
static int lastDrdyState = -1;
static uint32_t framesThisSecond = 0;
static uint32_t rawCh[4] = {0, 0, 0, 0};
static int32_t ain2Min = INT32_MAX;
static int32_t ain2Max = INT32_MIN;
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

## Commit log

2026-02-05 Add ESP32-targz library and implement tar.gz log rotation
    Rotated log files are now compressed as .tar.gz archives using the
    ESP32-targz library, similar to Linux logrotate. During compression,
    the Logger temporarily swaps from SdFat to Arduino SD (required by
    ESP32-targz's fs::FS interface), then restores SdFat for normal
    operation. Falls back to plain rename if compression fails.
    [Logger.cpp]
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2026-02-05 Fix OutPin callback return value logic consistency
    Changed turnOff(), turnOn(), and turnOn(float) to match turnOnPercent()
    callback behavior. Now all methods consistently:
    - Return early if callback returns false (cancel operation)
    - Proceed if callback returns true (enable/restart task)
    This fixes the issue where the task scheduler callback wasn't being
    called because turnOn() was returning early when callback returned true.
    [OutPin.cpp]
2026-02-06 Cleaned up new code and tested on board
    - Replace delay() with vTaskDelay(pdMS_TO_TICKS()) for FreeRTOS compatibility
    - Fix OutPin callback return value logic consistency
    - Code cleanup and refactoring
    [InputPin.cpp, Logger.cpp, OutPin.cpp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]
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2026-02-07 Add automatic defrost after 90-min HEAT runtime with condenser temp check
    Triggers software defrost when CONDENSER_TEMP < 33°F after 90 min accumulated
    CNT runtime in HEAT mode. Exits when condenser > 42°F or 15-min safety timeout.
    Rechecks every 10 min if temp is OK. Runtime persists to SD card every 5 min
    and restores on boot. Switching to COOL resets accumulated runtime.
    [Config.cpp, GoodmanHP.h, main.cpp]
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2026-02-08 Add DFT emergency defrost with 5-min minimum and HEAT-only trigger
    DFT input (external sensor < 41°F) now only triggers DEFROST from HEAT
    mode. Latches on with 5-min minimum runtime, then monitors CONDENSER_TEMP
    to exit when > 42°F or 15-min safety timeout. Resets heat runtime on
    completion.
    [GoodmanHP.h]
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2026-02-08 Fix OutPin::initPin() to drive pin OFF immediately after pinMode
    initPin() now writes the pin to its OFF state (inverse-aware) right
    after pinMode, before any callback logic. This prevents pins from
    floating HIGH on startup. Removed manual W pin workaround from setup().
    [OutPin.cpp, main.cpp]
2026-02-08 Fix async_tcp watchdog timeout by removing blocking MQTT connect loop
    The tConnectMQQT task had a blocking while(!connected) loop with
    vTaskDelay that starved the async_tcp FreeRTOS task, triggering the
    watchdog. Now checks connection state non-blockingly each second and
    relies on the onMqttConnect callback to disable the reconnect task.
    [main.cpp]
2026-02-08 Disable AsyncTCP task watchdog to fix async_tcp panic
    AsyncTCP's header defaults CONFIG_ASYNC_TCP_USE_WDT=1, subscribing the
    async_tcp FreeRTOS task to the ESP-IDF 5s watchdog. When the MQTT broker
    is slow or unreachable, the task cannot reset in time, triggering abort().
    Adding -DCONFIG_ASYNC_TCP_USE_WDT=0 to build flags prevents registration.
    Also removes unnecessary disconnect(true) before MQTT connect and defers
    NTP sync to scheduler instead of blocking during setup().
    [WebHandler.cpp, main.cpp]
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2026-02-08 Fix NTP sync not triggering on WiFi connect
    NTP task was auto-enabled at startup before WiFi connected, failed
    silently, then waited 2 hours to retry. Now the task starts disabled
    and is enabled via startNtpSync() when WiFi connects, ensuring
    timestamps appear in logs immediately after connection.
    [WebHandler.cpp, main.cpp]
2026-02-08 Fix NTP sync: trigger on GOT_IP event and run immediately
    Two issues prevented NTP from working:
    1. enableDelayed() waited the full 2-hour interval before first sync;
    changed to enable() for immediate execution
    2. NTP was triggered on STA_CONNECTED (no IP yet) instead of
    STA_GOT_IP (has IP, can reach NTP servers)
    [WebHandler.cpp, main.cpp]
2026-02-09 Add configurable timezone for NTP/RTC time sync
    Replace hardcoded UTC offsets with configurable gmtOffset and
    daylightOffset fields in ProjectInfo, persisted to SD card JSON config.
    Defaults to US Central (UTC-6, DST +1hr). Also adds getWiFiIP() helper
    and switches input/output pin callbacks to use Logger.
    [Config.cpp, WebHandler.cpp, main.cpp]
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2026-02-09 Fix W relay being forced on by stray digitalWrite in idle status
    Removed digitalWrite(_WPin, HIGH) in printIdleStatus() that was
    bypassing OutPin control and forcing W on every 10 seconds.
    [main.cpp]
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2026-02-10 Add LPS fault protection with ERROR state and MQTT fault telemetry
    LPS LOW triggers State::ERROR, shuts down CNT immediately, and blocks
    state updates until pressure restores. Publishes fault events on
    goodman/fault topic and includes lpsFault in goodman/state payload.
    [GoodmanHP.h, MQTTHandler.cpp, main.cpp]
2026-02-10 Add I2C bus support with startup scan and /i2c/scan API endpoint
    Initialize Wire on GPIO8 (SDA) / GPIO9 (SCL), scan for devices at
    boot, and add GET /i2c/scan route. Fix dangling pointer in
    getWiFiIP() by storing IP string in member variable.
    [WebHandler.cpp, main.cpp]
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2026-02-10 Add MCP9600 I2C thermocouple for LIQUID_TEMP, rename LINE_TEMP to COMPRESSOR_TEMP
    The existing OneWire LINE_TEMP sensor tops out at ~185°F, insufficient for
    liquid line temps exceeding 400°F. Replace with MCP9600 I2C thermocouple
    amplifier (Type-K, address 0x67) as LIQUID_TEMP. Repurpose the OneWire
    sensor at index 0 as COMPRESSOR_TEMP for compressor body monitoring.
    TempSensor now encapsulates MCP9600 support: setMCP9600() stores the
    pointer, and update() auto-routes to read the thermocouple when set.
    This keeps GoodmanHP's temp loop uniform across all sensor types.
    Also includes previously uncommitted low temp protection config persistence
    (lowTemp.threshold in Config JSON, lowTemp in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
    [Config.cpp, GoodmanHP.h, MQTTHandler.cpp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]
2026-02-11 Add compressor overtemp protection, defrost condenser recheck, and OutPin hardware validation
    - Compressor over-temperature protection: shutdown CNT at 240°F, resume at 190°F,
    keep FAN on, log fault and resolution time. Highest priority fault check.
    - Defrost condenser recheck every 1 minute with logging during active defrost
    - OutPin isOn() cross-checks hardware pin state vs software state, logs mismatches
    - Added _transitioning flag to prevent false mismatch warnings during pin state changes
    - compressorOverTemp field added to MQTT state payload
    [GoodmanHP.h, MQTTHandler.cpp, OutPin.cpp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]
2026-02-11 Fix IPAddress printing and improve OutPin PWM/transition handling
    - Fix IPAddress raw uint32_t printing in WiFi IP and MQTT host logs
    - Add PWM hysteresis to isPinOn() (800 on / 400 off) with inverse support
    - Wrap turnOnPercent() with _transitioning flag to prevent false state mismatch warnings on delayed task callbacks
    [Config.cpp, OutPin.cpp, main.cpp]
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2026-02-11 Rework defrost logic: DFT gates runtime accumulation, exit at 60°F
    - Heat runtime only accumulates when DFT is active (closed at 32°F)
    - DFT turning off clears accumulated runtime (no ice risk above 32°F)
    - Defrost exit temp raised from 41°F to 60°F
    - Removed DFT emergency defrost trigger (DFT now gates accumulation only)
    - Only COOL and DEFROST clear runtime; Y going off does not
    [GoodmanHP.h]
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2026-02-11 Add web-based configuration page with password obfuscation
    - GET /config serves HTML form for WiFi, MQTT, timezone, low temp threshold, logging
    - GET /config?format=json returns current config with masked passwords
    - POST /config saves changes: live settings apply immediately, WiFi/MQTT trigger reboot
    - Password changes require entering current password for verification
    - Passwords stored obfuscated (XOR + base64 with $ENC$ prefix) on SD card
    - Existing plaintext passwords auto-migrate to obfuscated on first save
    - Config.updateConfig() for full config persistence (follows updateRuntime pattern)
    - Timezone displayed in hours on config page, stored as seconds internally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
    [Config.cpp, WebHandler.cpp, main.cpp]
2026-02-11 Add HTTPS server for secure /config and /update endpoints
    Self-signed ECC P-256 cert loaded from SD card (/cert.pem, /key.pem).
    ESP-IDF esp_https_server on port 443 serves sensitive endpoints while
    AsyncWebServer on port 80 redirects to HTTPS. Graceful fallback to
    HTTP-only when no certificates are present. HTTPS handlers isolated
    in separate TU (HttpsServer.cpp) to avoid enum conflicts between
    esp_http_server.h and ESPAsyncWebServer.h.
    [Config.cpp, Logger.cpp, WebHandler.cpp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]
2026-02-11 Fix password obfuscation key: use stable key and set before config load
    The obfuscation key was compile_date which changed every build, breaking
    stored passwords after firmware updates. Also moved setObfuscationKey()
    before loadTempConfig() so passwords are actually decoded during load.
    [main.cpp]
2026-02-11 Add AES-256-GCM password encryption, SD card web pages, and FTP server
    Replace XOR password obfuscation with AES-256-GCM using eFuse HMAC-derived
    key (backward compatible with $ENC$ legacy format). Serve HTML pages from
    /www/ on SD card instead of inline C++ strings, enabling UI changes without
    firmware reflash. Add SimpleFTPServer (STORAGE_SD mode) on port 21 for
    uploading files to SD card over the network.
    [Config.cpp, WebHandler.cpp, main.cpp]
2026-02-11 Fix SPI bus conflict between FTP (Arduino SD) and web file serving (SdFat)
    Call SD.begin()/end() on demand when enabling/disabling FTP, and
    re-initialize SdFat after FTP stops so web page serving resumes.
    [main.cpp]
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2026-02-11 Disable FTP auto-start at boot and prompt for IP in scripts
    FTP no longer starts automatically — only on demand from config
    page or scripts. Fixes SPI bus conflict that blocked web page
    serving after every reboot. Scripts now prompt interactively for
    device IP and admin password.
    [main.cpp]
2026-02-11 Add HTTPS handlers for /heap and /log, fix SdFat re-init after FTP
    Registered / (root), /log, and /heap on HTTPS server. Bumped max
    URI handlers to 16. Fixed SdFat re-init using correct SPI speed
    (SD_SPI_SPEED=50MHz) after FTP disable.
    [main.cpp]
2026-02-11 Migrate from SdFat to Arduino SD, add /temps HTTPS handler, startup lockout
    Replace dual SD library (SdFat + Arduino SD) with single Arduino SD library
    throughout. Eliminates SPI bus swap pattern that caused bugs when toggling
    FTP (broken web serving, wrong SPI speed on re-init). Add /temps endpoint
    to HTTPS server. Add 3-min startup lockout for sensor stabilization. Fix
    nav brand text color on all HTML pages.
    [Config.cpp, GoodmanHP.h, Logger.cpp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]
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2026-02-11 Add OTA update progress bar and switch to raw body upload handler
    Replace the bare HTML form with XHR-based upload that shows file info,
    a progress bar with percentage, and reboot countdown on success. Switch
    the HTTP /update POST handler from multipart upload to raw body handler
    to match the application/octet-stream content type sent by the XHR.
    [WebHandler.cpp]
2026-02-11 Add firmware backup to SD before OTA and revert-to-previous support
    Before each OTA update, the running firmware is read from flash and
    saved to /firmware.bak on the SD card. A new /revert endpoint lets
    the user flash the backup back, with a revert button on the update
    page. Shared backup/revert logic lives in OtaUtils to avoid
    duplication between HTTP and HTTPS handlers. Also adds an
    ota-update.sh script for CLI-based OTA upload and revert.
    [WebHandler.cpp]
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2026-02-11 Decouple OTA upload from flash: save to SD first, apply separately
    Upload now saves firmware to /firmware.new on SD card (no reboot),
    then a separate Apply step backs up current firmware and flashes from
    SD — same proven pattern as Revert. Fixes unreliable browser response
    when upload and flash happened concurrently in the HTTPS handler.
    [WebHandler.cpp]
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2026-02-11 Add startup lockout and short cycle protection indicators to dashboard
    Expose isStartupLockoutActive() and isShortCycleProtectionActive() as
    public methods on GoodmanHP. Include both flags in /state JSON response
    (HTTP and HTTPS). Add Startup and Short Cycle pills to dashboard UI.
    [GoodmanHP.h, WebHandler.cpp]
2026-02-11 Add reboot button to nav bar and /reboot POST endpoint
    Red reboot button floated right in nav on all pages. Requires auth,
    confirms before rebooting. HTTPS and HTTP handlers with 2s delayed
    reboot.
    [WebHandler.cpp]
2026-02-11 Add countdown timer to Startup Protect pill on dashboard
    New getStartupLockoutRemainingMs() method exposes remaining lockout
    time. /state JSON includes startupLockoutRemainSec field. Dashboard
    pill shows "Startup Protect: Xm" during lockout, reverts to plain
    "Startup Protect" (green) when complete.
    [GoodmanHP.h, WebHandler.cpp]
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2026-02-12 Add WiFi AP fallback mode with secret-based AP password
    After 20 min of failed WiFi, switches to AP mode (SSID: GoodmanHP).
    AP password sourced from build-time secret (secrets.ini, gitignored)
    via AP_PASSWORD define. Credentials logged overtly at WARN level.
    Web server accessible at 192.168.4.1 for OTA recovery and config.
    apMode field added to /state JSON endpoint.
    [WebHandler.cpp, main.cpp]
2026-02-12 Add WiFi scan and test-before-save page
    New /wifi/view page with network scanner, signal strength bars, and
    connect-with-verify flow. Tests new WiFi credentials asynchronously
    (15s timeout), saves to config only on successful connection, reverts
    on failure. HTTPS endpoints for /wifi/view and /scan. Scan WiFi
    button added to config page WiFi fieldset.
    [WebHandler.cpp]
2026-02-12 Add HTTPS handlers for /wifi/test, /wifi/status, and /scan
    WiFi test and status endpoints were missing from the ESP-IDF HTTPS
    server (port 443), causing JSON parse errors when the page was served
    via HTTPS. Added full /wifi/test POST, /wifi/status GET, and /scan GET
    handlers to HttpsServer.cpp with shared state via HttpsContext pointers.
    [WebHandler.cpp]
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2026-02-12 Add dark/light theme, stable XOR key, build date on dashboard
    - Dark/light theme with shared theme.css, persisted to config, instant
    preview on config page, localStorage cache for flash-free loads
    - Move XOR obfuscation key from compile_date to stable secrets.ini
    XOR_KEY so encrypted passwords survive OTA firmware updates
    - Show firmware build date in dashboard System card and /state JSON
    - Fix Basic auth (requestAuthentication was defaulting to Digest)
    - Add HTTPS redirects for /, /dashboard, /log/view, /heap/view
    - Add /theme.css and /theme API endpoints
    - Simplify password encryption: remove $HASH$ scheme, unify admin
    password to use same $AES$/$ENC$ encryption as WiFi/MQTT
    - Defaul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
    [Config.cpp, WebHandler.cpp, main.cpp]
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2026-02-13 Add defrost RV fail detection, transition short cycle, and config restructure
    - Detect high suction temp (>=140°F default) during defrost as RV failure,
    latch fault to block CNT until manually cleared via config page
    - Add 30s pressure equalization delay before engaging RV+CNT in defrost
    - Restructure config JSON: move lowTemp into heatpump parent section with
    highSuctionTemp, shortCycle sub-objects; auto-migrate old format on load
    - Make CNT and RV short cycle delays configurable via config page
    - Add rvFail/highSuctionTemp/defrostTransition to /state, MQTT, dashboard
    [Config.cpp, GoodmanHP.h, MQTTHandler.cpp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]
2026-02-13 Add pin table page with manual override for output control
    New /pins page displays inputs, outputs, and temperatures in a table.
    Manual override mode (30-min auto-timeout) allows toggling outputs
    directly while bypassing the state machine. CNT enforces short cycle
    protection in manual mode. Auth required for page access; single auth
    prompt when enabling lockout covers the entire session. Nav bar updated
    on all pages.
    [GoodmanHP.h, MQTTHandler.cpp, WebHandler.cpp]
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2026-02-13 Add force defrost button to pins page
    Force Defrost button on pins page triggers software defrost from HEAT mode
    with validation (no active faults, not in manual override). Defrost/transition
    status shown inline. Fixed pins page auth: refresh uses credentials for JSON
    polling, override toggle prompts for auth instead of "No active session" error.
    [GoodmanHP.h, WebHandler.cpp]
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2026-02-13 Implement 3-phase defrost output sequencing and COOL cancellation
    Split defrost entry into Phase 1 (pressure equalization, all off), Phase 2
    (RV+W on, CNT short cycle wait), and Phase 3 (CNT on, active defrost).
    Cancel defrost and clear heat runtime when thermostat switches to COOL mode
    during a pending defrost. Y drop during defrost restarts from Phase 1 on
    resume instead of immediately re-engaging outputs.
    [GoodmanHP.h, WebHandler.cpp]
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2026-02-13 Add 3-phase defrost exit transition for safe RV switching
    When defrost ends, instead of turning off CNT and RV simultaneously
    (which risks the compressor restarting before the reversing valve has
    physically seated back in heat position), implement a reverse 3-phase
    sequence: Phase 1 keeps RV+W on while CNT pressure equalizes, Phase 2
    switches RV+W off and waits for the valve to seat, then CNT+FAN
    resume in HEAT mode. Y drop during exit cancels the transition.
    [GoodmanHP.h, WebHandler.cpp]
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2026-02-13 Persist _softwareDefrost across reboots via config JSON
    Follows the rvFail persistence pattern: added softwareDefrost to ProjectInfo,
    persisted to heatpump.defrost.active in config JSON, saved via tSaveRuntime
    (every 5 min with change detection), and restored on boot with a simple setter
    so defrost resumes from Phase 1 when Y activates in HEAT mode.
    [Config.cpp, GoodmanHP.h, main.cpp]
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2026-02-19 Auto-generate self-signed SSL cert when missing or expired
    On boot, if cert.pem/key.pem are absent from SD card, generates an ECC
    P-256 self-signed certificate (CN=ESP32, 10-year validity) using mbedTLS
    and saves to SD. After NTP sync, checks expiration and regenerates if
    needed. Eliminates manual cert provisioning — HTTPS works out of the box.
    [Config.cpp, WebHandler.cpp, main.cpp]
2026-02-19 Preserve WiFi, MQTT, admin credentials and certs on SD format
    Format now only wipes runtime state and data files. Network credentials,
    admin password, and SSL certificates are restored to the fresh SD card
    so the device stays accessible after a format + reboot.
    [Config.cpp]
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2026-02-19 Add SSD1306 I2C OLED display support (128x64)
    Adds a DisplayManager class that drives a 128x64 SSD1306 OLED on the
    existing I2C bus (0x3C) to provide at-a-glance status without network
    access. The display cycles through 5 pages (status, temps, I/O, system,
    protections) with configurable page flip interval (3-60s) and
    enable/disable control, both persisted to SD config and adjustable live
    from the web config page.
    [Config.cpp, DisplayManager.cpp, WebHandler.cpp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]
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2026-02-19 Avoid bare I2C probe on MCP9600 to prevent chip crash
    Some MCP9600 chips crash when probed with address-only I2C transactions
    (beginTransmission/endTransmission with no data). Once crashed, the chip
    locks up the I2C bus until power cycled.
    Fix: initialize MCP9600 via its driver (which reads Device ID register)
    before the I2C scan, skip 0x67 in the scan loop, and use full register
    reads in the /i2c/scan web endpoint.
    See: https://forums.adafruit.com/viewtopic.php?t=163742
    [WebHandler.cpp, main.cpp]
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2026-02-20 Add MAX6675 SPI thermocouple support and state machine enhancements
    Add MAX6675 as third-tier LIQUID_TEMP fallback (OneWire > MCP9600 > MAX6675)
    with configurable GPIO pins (CLK/CS/DO), failure counter, and web UI config.
    Also includes state table validator, HEAT→COOL transition sequencing,
    configurable W/AUX in LOW_TEMP, and pins page SPI sensor display.
    [Config.cpp, GoodmanHP.h, WebHandler.cpp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]
2026-02-21 Favor MAX6675 over other thermocouple sources for LIQUID_TEMP
    Priority is now MAX6675 SPI > MAX31850K OneWire > MCP9600 I2C.
    If MAX6675 is detected, it replaces any OneWire LIQUID_TEMP sensor.
    [main.cpp]
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2026-02-21 Add 3D shell files to repo with flipped mating profile and 3.5mm walls
    Moved shell STEP/STL files and FreeCAD modification scripts into shell/
    directory. Walls thickened from 3mm to 3.5mm, mating tongue moved from
    top to bottom shell to prevent layer separation during 3D printing.
    Wall cutouts preserved. README updated with shell documentation.
    [3DShell_GoodmanHPv3_B_3.5mm_flipped.step, 3DShell_GoodmanHPv3_B_3.5mm_flipped.stl, 3DShell_GoodmanHPv3_B_3mm.step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]
2026-02-22 Drill M1.5 screw holes in modified shells at wall midpoints
    Original EasyEDA screw holes at Y=32.32, Z=32.65 (wall Y-midpoint,
    mating zone center) were lost during the tongue/groove profile flip
    because they were in the inner lip material that got cut away. Drills
    matching 1.5mm through-holes in both top and bottom modified shells
    at the same location so screws align when assembled.
    [3DShell_GoodmanHPv3_B_3.5mm_flipped.step, 3DShell_GoodmanHPv3_B_3.5mm_flipped.stl, 3DShell_GoodmanHPv3_T_3.5mm_TC_flipped.step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]
2026-02-22 Reposition LCD cutout: shift up 2mm bottom, 1mm top (27x16mm)
    Original EasyEDA cutout at Y=[59.59,76.59] (27x17mm) was 2mm too low
    on the bottom edge and 1mm covering the screen on top. Plugged old
    cutout and recut at Y=[61.59,77.59] (27x16mm). Standoffs preserved
    in their original positions. Rebuilt from scratch to avoid residual
    thin layers from plug/cut Z mismatch.
    [3DShell_GoodmanHPv3_T_3.5mm_TC_flipped.step, 3DShell_GoodmanHPv3_T_3.5mm_TC_flipped.stl]
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2026-02-22 Add debossed labels, named features, and MAX6675 mount template
    - cutout.py: add deboss_text(), emboss_text(), max6675_mount(), and
    _make_text_solid() helper (TrueType font support, multi-wire glyphs)
    - modify_top.py: replace magic numbers with FEATURES dict (LV, HV, TC,
    LCD), use max6675_mount() for TC pillar, deboss "24v Signal Wires",
    "240 V", "+/-" polarity, and "Liquid Line" labels on ceiling
    - modify_bottom.py: add BOTTOM_FEATURES dict (ACCESS, VENT, ANTENNA)
    - shell/README.md: document shell dimensions, features, and cutout.py API
    [3DShell_GoodmanHPv3_T_3.5mm_TC_flipped.step, 3DShell_GoodmanHPv3_T_3.5mm_TC_flipped.stl]
2026-02-22 Fix text rendering and restore pillar position
    - cutout.py: use Part.makeFace with FaceMakerBullseye for multi-wire
    glyphs — fixes missing characters (0, 4, a, q) that failed with
    face-level boolean cuts
    - modify_top.py: restore M3 pillar to original position below TC cutout
    (bb.XMin+35, bb.YMax-30) instead of inside it; increase label depth
    to 0.8mm and font height to 5mm for slicer visibility
    [3DShell_GoodmanHPv3_T_3.5mm_TC_flipped.step, 3DShell_GoodmanHPv3_T_3.5mm_TC_flipped.stl]
2026-02-22 Add shell templates and fix screw hole positions
    - Add labeled_cutout() and wall_opening() reusable templates to cutout.py
    - Fix max6675_mount() to use absolute pillar coords (was placing inside cutout)
    - Increase TC pillar height from 3mm to 6mm for proper board clearance
    - Move M1.5 enclosure screw holes to Z=30.0 (2mm above lip edge)
    - Refactor bottom shell to use wall_opening() loop over BOTTOM_FEATURES dict
    - Update README with new function reference entries
    [3DShell_GoodmanHPv3_B_3.5mm_flipped.step, 3DShell_GoodmanHPv3_B_3.5mm_flipped.stl, 3DShell_GoodmanHPv3_T_3.5mm_TC_flipped.step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]
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
